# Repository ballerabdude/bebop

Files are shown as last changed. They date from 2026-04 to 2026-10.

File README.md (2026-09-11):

# Bebop

Bebop is an NVIDIA Jetson–based robot platform. This monorepo contains
everything needed to design, simulate, build, provision, and update a fleet
of Bebop robots — plus the customer-facing companion app.

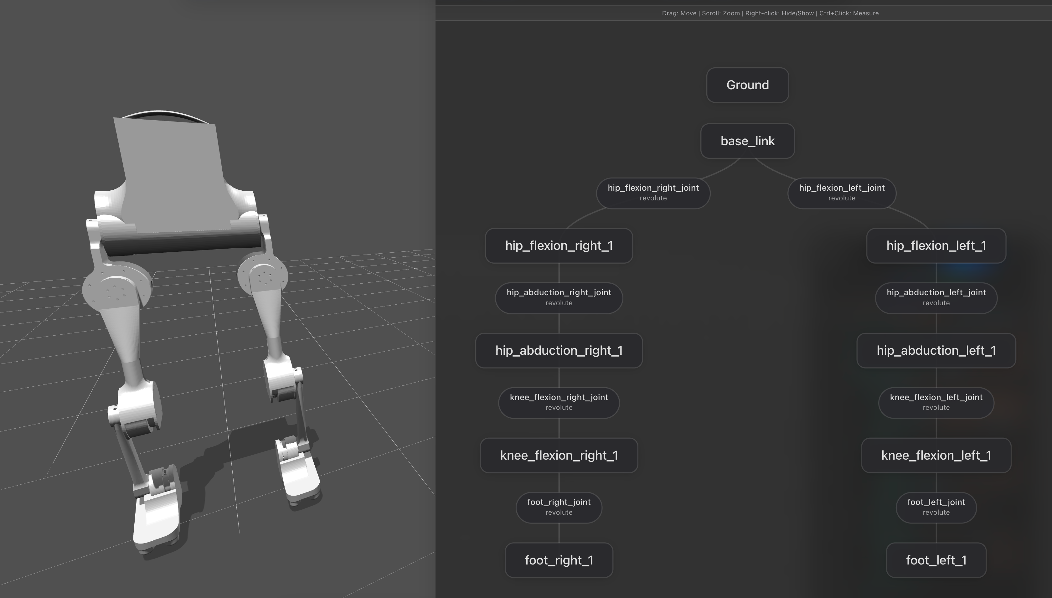
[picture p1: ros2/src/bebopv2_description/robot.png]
Bebop robot


## High-Level Architecture

```
 ┌────────────────────┐  SoftAP + WS :9091  ┌──────────────────────────┐
 │  Mobile App        │ ──────────────────▶ │  bebop-agent (Rust)      │
 │ (iOS / Android)    │ ◀──── status ────── │  running on Jetson       │
 └─────────┬──────────┘                     │  ┌────────────────────┐  │
           │  Wi-Fi / LAN                    │  │ Wi-Fi provisioner  │  │
           │                                 │  │ SoftAP fallback    │  │
           │  runtime WS :9090               │  │ Setup server       │  │
           ▼                                 │  └────────────────────┘  │
 ┌────────────────────┐                      └──────────────────────────┘
 │  bebop-linux       │
 │  (Rust firmware)   │──── SocketCAN ── motors
 └────────────────────┘
```

## Repository Layout

| Path | Purpose |
|---|---|
| `jetson-flash/` | One-time host-side provisioning: downloads NVIDIA L4T and flashes a fresh Jetson Orin Nano over USB. Runs once per device. |
| `jetson-agent/` | Rust workspace + on-device deployables. `bebop-agent` provisioning daemon (Wi-Fi + SoftAP), `bebop-proto` (setup wire format), `deploy/` (systemd + install scripts). |
| `bebop-app/` | Customer-facing companion app (Tauri 2 + React + TypeScript). Desktop / iOS / Android. |
| `firmware/` | Embedded firmware: `bebop-linux/` (Rust runtime) and `bebop-locomotion/` (PlatformIO). C/C++ tooling pinned via `firmware/.clangd`. |
| `bebop-vision/` | Robot vision stack: SAM 3.1 teacher pipeline (dataset auto-labeling + distillation) and the SegFormer navigable-path student, sector planner, and drive tooling. See `bebop-vision/README.md`. |
| `sim/` | Isaac Sim / Isaac Lab containers, the `bebop_training` Python RL extension, and `usd/` scene assets. Runs off-robot on a workstation with an NVIDIA GPU. |
| `ros2/` | ROS 2 Jazzy workspace used on the dev workstation: `src/bebop_pilot`, `src/bebopv2_description` (URDF), and the dev container under `docker/`. |
| `docs/` | Cross-cutting docs: architecture, setup protocol, onboarding, hardware reference. |
| `docker-compose.yml`| Orchestrates the dev-workstation containers (`ros2_docker`, `isaac_sim`, `isaac_lab`) under the `sim` / `lab` profiles. |
| `justfile` | Convenience recipes (`just check`, `just build-jetson`, `just sim-up`, `just lab-up`, ...). |
| `.github/` | CI workflows. |

## Getting Started

Read [`docs/onboarding.md`](docs/onboarding.md) for dev setup, your first
build, and how to deploy to a real Jetson. Then `docs/architecture.md`
shows how the on-robot pieces connect.

```sh
just                # list available recipes
just check          # workspace-wide cargo check (jetson-agent)
just build-jetson   # native arm64 build of the agent (run on arm64 Linux)
just app-dev        # run the mobile app in Tauri dev mode
just sim-up         # bring up Isaac Sim + ROS 2 dev container
just lab-up         # bring up Isaac Lab + ROS 2 dev container
```

## Naming

The robot product is **Bebop**. The on-device daemon is **bebop-agent**.
The companion app is also called **Bebop** (binary: `bebop-app`).

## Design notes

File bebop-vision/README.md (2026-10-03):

# bebop-vision

Data-collection and dataset-labeling stack for the bebop robot: the
Orbbec RGB-D rig is recorded into **navd MCAP sessions** (dual-camera
color + lossless depth + cmd_vel/odom/goal + a geometric BEV teacher
grid), auto-labeled with SAM 3.1 floor concepts fused by measured depth,
and reviewed/corrected in a dashboard — the dataset any navigation
approach (learned or classical) trains and evaluates from.

This tree intentionally carries **no driving code**. Drive the robot
from the app (manual teleop); the recorder captures whatever you do.
The navigation research (BEV student, end-to-end trajectory student,
TensorRT runtime) lives on the `exp/navd-ai-20260909` branch.

## How a session becomes training data

```
 record            extract              SAM 3.1 labels          fuse                    review
 teleop + app ----> navd MCAP  --------> tools/sam_floor_label -> tools/fuse_navd_labels -> dashboard
 goals + odom      (tools/             (floor/carpet/rug/     (SAM floor gated by     (paint corrections
 (app Navigate)    mcap_extract.py)    ground per camera)     measured depth -> 60x60  as `hand` labels)
                                                              teacher per tick)
```
(The recorded MCAP carries no BEV grid — labels are generated purely
from SAM × measured depth.)

- **Record** — `main.py --record-navd <dir> --auto` opens/closes MCAP
  segments with the drive state (wheels armed, no estop) and prunes under
  a disk budget. Navigation goals from the app are recorded per tick —
  **teleop toward an active waypoint**: goals in the data are the signal
  goal-following models train on.
- **Extract** — `tools/extract_all_navd.py` unpacks MCAPs into
  `datasets/navd-v0/<session>/{color,color_far,depth,labels,manifest.jsonl}`.
- **Label** — `tools/sam_floor_label.py near|far` prompts SAM 3.1 with
  drivable-ground concepts per frame; `tools/fuse_navd_labels.py` gates
  SAM's floor by measured depth into a 60×60 teacher grid per tick
  (`blocked / navigable / caution`).
- **Review** — `tools/dashboard_api.py` (dashboard UI): replay ticks,
  compare fused teacher vs prediction overlays, paint corrections as
  additive `hand` labels. A session counts when it passes review.

## Layout

| Path | Purpose |
|---|---|
| `main.py` | Entry point: navd MCAP recorder (rig + operator video + goals) |
| `bebop_vision/orbbec.py` | Orbbec rig: cameras, sync, intrinsics, rig YAML |
| `bebop_vision/camera.py` | Threaded MJPEG/RTSP/file consumer with reconnect |
| `bebop_vision/robot.py` | Protobuf-over-WS runtime client (telemetry, goals) |
| `bebop_vision/videoserver.py` | Operator WebRTC (WHEP) streams (`:9092/whep?stream=...`) |
| `bebop_vision/whep.py` | webrtcbin H.264 pipeline + offer/answer per client |
| `bebop_vision/recorder_mcap.py` | navd MCAP writer (10 Hz ticks, shared log_time) |
| `bebop_vision/sam3_concepts.py` | SAM 3.1 text-prompted concept segmenter (teacher) |
| `bebop_vision/goals.py` | Navigation-goal slot (heading / odom point) |
| `tools/mcap_extract.py` | MCAP session -> navd-v0 training layout |
| `tools/extract_all_navd.py` | Extract + audit every mirrored session |
| `tools/sam_floor_label.py` | SAM 3.1 floor labels per extracted session |
| `tools/fuse_navd_labels.py` | SAM × depth -> fused 60×60 teacher grids |
| `tools/dashboard_api.py` | FastAPI backend for the review dashboard |
| `dashboard/` | Review dashboard (React): replay, overlay, hand painting |
| `tools/set_self_mask.py` | Chassis self-view mask painter |
| `tools/orbbec_imu_probe.py` | Camera IMU (accel/gyro) profiles + depth-clock offset probe |
| `weights/` | Checkpoints (gitignored) |
| `datasets/` | Extracted datasets (gitignored) |

Navigation research (BEV student, trajectory student, TensorRT runtime,
drive paths) lives on the `exp/navd-ai-20260909` branch — including its
own README additions and `docs/navd-traj.md`.

## Install

Robot + workstation runtime:

```sh
python -m venv .venv
.venv/bin/pip install -e .
```

Labeling side (workstation with NVIDIA GPU — SAM 3.1 teacher):

```sh
.venv/bin/pip install "sam3 @ git+https://github.com/facebookresearch/sam3.git" psutil
# sam3 pulls torchvision from PyPI, which will NOT match a cu128 torch build.
# Reinstall it from the same index torch came from, e.g.:
.venv/bin/pip install --force-reinstall --no-deps "torchvision==0.26.0+cu128" \
    --index-url https://download.pytorch.org/whl/cu128
```

### Model weights

The robot does not ship weights. `config/models.yaml` is the catalog (shared
with the firmware): each entry is either `kind: hf` (download from Hugging
Face) or `kind: local` (trained on the robot, or copied from a workstation
with `scp`), and carries a `purpose` (e.g. `segmentation`, `backbone`,
`navigation`). Models sharing a purpose are alternatives. Add a model by
appending a catalog entry — no code changes.

**From the app (recommended):** *Configure models* on the Dashboard, the
Motor Bench footer (or the direct-connect screens) opens the **Models**
screen. It lists the catalog grouped by purpose, downloads on demand, and
lets the operator pick the active model per purpose. Gated entries need a
Hugging Face token, which the app sends to the robot (stored root-only at
`/etc/bebop/hf_token`, never echoed back). The token's account must have
accepted each model's license first, e.g.
<https://huggingface.co/facebook/sam3.1>. The purpose→model choice is
persisted at `/etc/bebop/model_selection.json` for the runtime to read. The
robot must be in Known Network (client) mode with internet during the
download; the firmware drives `bebop-model-download@<id>.service` and streams
progress into telemetry.

**On the workstation / by hand:**

```sh
# Put HF_TOKEN in .env (gitignored) or export it, then:
.venv/bin/python -m bebop_vision.download_model sam3.1   # one catalog id
.venv/bin/python -m bebop_vision.download_model --all    # every hf entry

# Legacy compatibility wrapper (downloads sam3 + sam3.1):
.venv/bin/python -m bebop_vision.download_sam3
```

## Collecting data

1. On the Jetson: `.venv/bin/python main.py --record-navd /var/lib/bebop-captures --auto`
2. From the app: enable wheels, teleop. Segments open/close with the
   drive state automatically.
3. Follow `docs/data-collection.md` for the per-session protocol —
   especially **goal-conditioned legs** (app Navigate waypoint + teleop
   toward it), which are the rarest and most valuable kind of tick.
4. Pull to the workstation (`just pull-data`), extract + audit
   (`just extract`), then review in the dashboard
   (`tools/dashboard_api.py`, port 8099).

## License note

SAM 3.x code and weights (teacher tooling, `weights/sam3*.pt`) are Meta's
"SAM License" — commercial use and fine-tuning are permitted and you own
derivative works, but redistribution of SAM 3.x materials or derivatives
must carry the SAM License. Downstream artifacts you train from the
labels (e.g. distilled students) are plain torch artifacts with no such
restriction. See the header of `bebop_vision/sam3_concepts.py`.

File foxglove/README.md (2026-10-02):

# Foxglove tooling

Scripts and layout definitions for reviewing Bebop **policy capture** MCAP
recordings in [Foxglove](https://foxglove.dev/). Captures are now written as
**ROS2 CDR-encoded MCAP** (profile=`ros2`, schema=`ros2msg`, message=`cdr`)
by `firmware/bebop-linux/src/policy_capture.rs`.

## Quick start

1. Open an MCAP file in Foxglove Desktop.
2. Import a layout: **Layouts -> Import from file...** and choose one of the
   generated JSON files.
3. For the robot layout, set **Settings -> Desktop -> ROS_PACKAGE_PATH** to:
   ```
   /Users/ahagi/Documents/projects/bebop/ros2/src
   ```

Regenerate layouts after editing the Python sources:

```bash
python3 foxglove/make_foxglove_layout.py --layout all --force
```

## Channels

The ROS2 MCAP file contains 5 channels:

| Channel | ROS2 Type |
| --- | --- |
| `/joint_states` | `sensor_msgs/msg/JointState` |
| `/imu` | `sensor_msgs/msg/Imu` |
| `/policy/status` | `bebop_msgs/msg/PolicyStatus` |
| `/policy/observation` | `bebop_msgs/msg/Float32Stamped` |
| `/policy/action` | `bebop_msgs/msg/PolicyAction` |

## Layouts

### Robot (`bebop_robot_layout.json`)

- **3D panel** loads the URDF and animates from `/joint_states`
- **Plot panels** read from `/joint_states.position[]` / `.velocity[]`,
  `/imu.orientation` / `.angular_velocity`, with X axis `/policy/status.sim_time_s`

### Policy debug (`bebop_policy_layout.json`)

Same animated URDF **3D panel** as the robot layout, plus two plot columns
for debugging policy behavior tick by tick:

- **Inputs** (`/policy/observation.data[]`): base angular velocity,
  projected gravity, joint pos/vel (relative, scaled), and velocity
  commands — the exact 49-element vector fed to the network.
- **Outputs** (`/policy/action.*`): decoded position targets (rad), `kp`,
  and `kd`.

See `firmware/bebop-linux/src/observation.rs::build` for the observation
index layout.

### Noise (`bebop_noise_layout.json`)

2x2 mosaic for static-capture noise review.

### navd sessions (`bebop_navd_layout.json`)

Review layout for navd recorder-v2 MCAP sessions
(`bebop-vision/bebop_vision/recorder_mcap.py`). Image/video channels are
Protobuf-encoded Foxglove messages; the custom twist/odom/calib channels
are JSON:

- **Image panels**: `/color_near` + `/color_far` (`foxglove.CompressedVideo`
  H.265, hardware NVENC; falls back to `foxglove.CompressedImage` JPEG),
  `/depth_near` + `/depth_far` (16-bit PNG, turbo colormap)
- **Plots**: teleop twist `/cmd_vel.vx|.wz` (the imitation label), odometry
  `/odom.x|.y|.theta`

The protobuf encoding also lets the native [Rerun](https://rerun.io) viewer
open a session directly (`rerun <session>.mcap`): Rerun maps the color
channels to a `VideoStream` and the depth channels to images, decoding
H.265 via the system FFmpeg with no GPU. (The Rerun web viewer still needs
browser HEVC; Foxglove's WebCodecs has no software HEVC path.)

For the bebop_navd Rerun dashboard (camera grid + telemetry plots), open the
session through the launcher instead; it takes a local path or a capture URL
(cached under `~/.cache/bebop/captures`):

```bash
python rerun_dashboards/open.py \
    http://bebop.local:9090/captures/dl/navd_session_<stamp>.mcap
```

Plain `rerun <session>.mcap rerun_dashboards/bebop_navd.rbl` does *not*
apply the dashboard: the MCAP loader names the app after the file, and a
blueprint only applies to recordings with its own app id (`bebop_navd`).

Record a session on the robot, copy it off, open it here:

```bash
# robot
python main.py --record-navd /tmp/navd_sessions --seconds 600
# workstation
scp bebop@bebop.local:/tmp/navd_sessions/*.mcap datasets/sessions/
```

## MCAP noise analysis

```bash
pip install mcap
python3 foxglove/mcap_noise.py ~/bebop-captures/policy_capture_*.mcap
```

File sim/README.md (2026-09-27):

# sim/

Simulation, RL training, and 3D assets for Bebop. Everything in here runs
**off-robot** on a workstation with an NVIDIA GPU and Isaac Sim / Isaac Lab.

## Layout

| Path | What it is |
|---|---|
| `pyproject.toml` | Defines the `bebop_training` Python package (depends on `isaaclab`). |
| `bebop_training/`  | RL extension: agents, envs, experiments, model export. |
| `usd/` | USD scene assets (`bebopv2/` robot description for Isaac Sim). |
| `scripts/` | One-shot Isaac Sim utility scripts (run from the Script Editor). |
| `docker/` | Isaac Sim / Isaac Lab container image (single Dockerfile, two BASE_IMAGEs). |
| `logs/` | Training logs (gitignored). Bind-mounted into the Isaac Lab container. |
| `setup/thor/` | On-device Jetson AGX Thor (aarch64) training env: pinned native Isaac Lab + GR00T installers. See [`setup/thor/README.md`](setup/thor/README.md). |

## Containers

The Isaac Sim and Isaac Lab containers are defined in the repo-root
`docker-compose.yml` and built from `sim/docker/Dockerfile` (the same image
recipe is reused with two different `BASE_IMAGE` args).

When the container starts, `sim/docker/entrypoint.sh` pip-installs the
`bebop_training` package in editable mode from `/workspace/bebop_bot/sim`,
which is the bind-mounted host path of this folder.

## Thor (aarch64) on-device training

The containers above are x86_64. To train **on the robot** (Jetson AGX Thor),
use the pinned native environment under [`setup/thor/`](setup/thor/README.md):

```sh
just thor-isaaclab          # install/refresh Isaac Sim + Isaac Lab on the Thor
just thor-train --task Isaac-Ant --num_envs 256
just thor-groot             # install/refresh the GR00T N1.7 VLA stack
```

There is no official aarch64 Isaac Sim container, so Thor uses a venv instead
of `sim/docker`; GR00T uses NVIDIA's upstream Thor installer. See
[`setup/thor/README.md`](setup/thor/README.md) for version pins, the verified
results on this robot, and the known Thor gotchas.

## Common commands

From the repo root:

```sh
just sim-up      # Isaac Sim + ROS 2 dev container (profile: sim)
just lab-up      # Isaac Lab + ROS 2 dev container (profile: lab)
just sim-down    # tear down sim profile
just lab-down    # tear down lab profile
```

Or directly with compose:

```sh
docker compose --profile sim up --build
docker compose --profile lab up --build
```

## URDF → USD import

After regenerating `ros2/src/bebopv2_description/urdf/bebopv2.urdf` (see
[`ros2/README.md`](../ros2/README.md) → "URDF mesh paths"), convert it
to USD headlessly inside the Isaac Lab container:

```sh
just lab-urdf-to-usd
```

That runs [`scripts/urdf_to_usd_bebopv2.py`](scripts/urdf_to_usd_bebopv2.py),
which converts the URDF into the layered asset at `usd/bebopv2/`
(wiping the previous generated copy — recoverable from git), applies the
post-import fixes from [`scripts/post_import_bebopv2.py`](scripts/post_import_bebopv2.py),
and prints a sanity report (joint completeness, link masses, measured
sole height vs. the configured spawn lift). The fixes:

- disable the fixed root joint the importer may add (we need a
  free-floating base for the biped),
- ensure `base_link` is a dynamic (not kinematic) rigid body,
- translate the robot up by 0.765 m so it spawns with its feet on the
  ground plane (the URDF's `base_link` frame is at the hip; the sole
  sits 0.7302 m below it at zero pose, +35 mm settle clearance),
- attach a 200 Hz IMU prim (`Imu_Sensor`) under
  `<robot>/Geometry/base_link`, matching the on-robot BNO085 placement
  so the policy sees the same `/imu/data` shape in sim and on hardware,
- bake `PhysxContactReportAPI` onto both foot prims so Isaac Lab's
  `ContactSensor` surfaces ground-contact events.

Both scripts are idempotent — safe to re-run. If you need the GUI
importer instead (manual fallback with the same settings), see
[`ros2/README.md`](../ros2/README.md) → "Importing the URDF into Isaac
Sim".

After converting, sanity-check the asset with `just lab-play
--num_envs 1` — the env's joint-order assertion fails fast if the
re-import shuffled joints.

## Sim-to-real contract (READ BEFORE TRAINING)

The Bebop V2 sim is pinned to the firmware's actual control behaviour, not
to whatever the motors *could* do mechanically. If you change either side
without changing the other, the trained policy will diverge on hardware.
Recent symptom of a divergence: "robot stands in sim, falls over instantly
on the real robot — feels weightless in sim".

The contract lives in three places that must agree:

| Quantity | Sim source of truth | Firmware source of truth |
|---|---|---|
| Per-joint policy kp/kd clamps | `POLICY_KP_MIN/MAX` and `POLICY_KD_MIN/MAX` in [`bebop_v2_base_cfg.py`](bebop_training/envs/bebop_v2_base_cfg.py) | `joints.<joint>.policy_gain_clamps` (per joint) + `defaults.policy_gain_clamps` in [`bebop_v2.yaml`](../firmware/bebop-linux/config/bebop_v2.yaml) |
| Per-joint torque cap (`effort_limit_sim`) | `FW_*_TAU_MAX` in `bebop_v2_base_cfg.py` | `joints.<joint>.hard_limits.tau_max` in `bebop_v2.yaml` |
| Per-joint velocity cap (`velocity_limit_sim`) | `FW_*_VEL_MAX` in `bebop_v2_base_cfg.py` | `joints.<joint>.hard_limits.vel_max` in `bebop_v2.yaml` |
| Setpoint slew on position channel (rad / 100 Hz tick) | `FW_MAX_POS_STEP_PER_TICK_RAD` in `bebop_v2_base_cfg.py`, applied via [`VariableImpedanceJointAction`](bebop_training/envs/bebop_v2_actions.py) | `defaults.slew.max_pos_step_per_tick` in `bebop_v2.yaml`, enforced in [`safe_send_ctrl`](../firmware/bebop-linux/src/safety/supervisor.rs) |
| Action / actuation latency | `FW_ACTION_DELAY_STEPS` ticks of action delay in `VariableImpedanceJointAction` | one CAN round-trip @ 100 Hz tokio tick in [`policy_runner.rs`](../firmware/bebop-linux/src/policy_runner.rs) |
| 52-dim observation / 24-dim MIT-mode action layout | [`ObservationsCfg`](bebop_training/envs/bebop_v2_base_cfg.py) | [`observation.rs`](../firmware/bebop-linux/src/observation.rs) and [`policy_runner.rs`](../firmware/bebop-linux/src/policy_runner.rs) |

If you tune any of those numbers (e.g. raise `max_pos_step_per_tick` to
let the policy move faster, or widen a `policy_gain_clamps` range after
a motor swap), update **both** sides and **retrain** — the policy bakes
in the achievable bandwidth and the kp/kd envelope, and a checkpoint
trained against one slew rate / clamp set will not transfer to another.

## Training

Training runs **inside the Isaac Lab container** (`bebop_isaac_lab`)
using [`train_bebop.py`](train_bebop.py) — a thin rsl_rl PPO entry
point that lives in this directory. At container start
`docker/entrypoint.sh` pip-installs `bebop_training` in editable mode,
which registers all the Bebop V2 Gym tasks so `--task` finds them.

Inside the container the script is at
`/workspace/bebop_bot/sim/train_bebop.py` (the repo is bind-mounted at
`/workspace/bebop_bot/`).

### Get a shell

```sh
just lab-up                   # bring up Isaac Lab + bebop_ros2 (profile: lab)
just lab-shell                # exec into bebop_isaac_lab
cd /workspace/bebop_bot/sim   # where train_bebop.py + bebop_training/ live
```

### Registered tasks

These IDs come from [`bebop_training/__init__.py`](bebop_training/__init__.py):

| Task ID | Cfg | What it trains |
|---|---|---|
| `Isaac-BebopV2-Standing-v0` | `BebopV2StandingCfg` | Minimal quiet-standing baseline (zero velocity command). |
| `Isaac-BebopV2-Standing-FixedGain-v0`  | `BebopV2StandingFixedGainCfg`  | Standing with kp/kd structurally frozen at midpoints. |
| `Isaac-BebopV2-Standing-Push-v0` | `BebopV2StandingPushCfg` | Standing + mid-episode pushes with a magnitude curriculum. |
| `Isaac-BebopV2-Standing-Push-ActNet-v0`| `BebopV2StandingPushActNetCfg` | Push-stand with the learned torque-response actuator (td-b05f58). |
| `Isaac-BebopV2-Mirror-v0` | `BebopV2MirrorCfg` | Visual hardware telemetry mirror (not for RL training). |

### Actuator-net (learned torque response)

The `ActNet` task swaps each `DCMotorCfg` group for a hybrid actuator
([`bebop_training/envs/bebop_v2_actuator_net.py`](bebop_training/envs/bebop_v2_actuator_net.py)):
analytic PD from the policy's live gains, then a learned cmd→realized-torque
response net (3×64 softsign MLP per Robstride motor model), then the usual
DC speed-torque envelope as a hard rail. Train the nets from the sysid logs
and smoke-test the integration before training:

```sh
# inside the Isaac Lab container, CWD=/workspace/bebop_bot/sim
/workspace/isaaclab/isaaclab.sh -p bebop_training/tools/actuator_net_fit.py
/workspace/isaaclab/isaaclab.sh -p scripts/verify_actuator_net.py --headless
```

The fit tool reads `bebop-sysid-logs/` and writes TorchScript nets +
`meta.json` (with net-vs-baseline RMSE) to `bebop_training/assets/actuator_nets/`.
Policy I/O is unchanged, so ActNet checkpoints deploy through the normal
ONNX path.

### Retraining after a sim-to-real fix

If you've just changed any of the `FW_*` constants in
`bebop_v2_base_cfg.py` (or the matching firmware fields in
`bebop_v2.yaml`), the existing checkpoints under `sim/logs/rsl_rl/` are
stale — they were trained against a different control surface and will
collapse on hardware. Retrain the curriculum from scratch (do not
`--resume` an old checkpoint that pre-dates the fix; it will hurt more
than it helps because the actor's converged action distribution is tuned
to the old physics).

The first stage (`Isaac-BebopV2-Flat-v0`) runs in ~45 min on a single
RTX 5090 at `--num_envs 4096`; the full curriculum is ~3 hours.

### Curriculum (recommended)

Train in sequence, warm-starting locomotion from the balance checkpoint.
The balance task is now a single merged stage that trains both standing
*and* push recovery (initial-condition randomisation + periodic lateral
pushes are wired into `BebopV2BaseEnvCfg.EventCfg`), so a separate
"robust" stage is no longer needed. See the long-form discussion in
[`experiments/exp_flat_balance_v2.py`](bebop_training/experiments/exp_flat_balance_v2.py)
and
[`experiments/exp_flat_locomotion_v2.py`](bebop_training/experiments/exp_flat_locomotion_v2.py).

```sh
# Stage 1 — stand + push recovery (single merged task)
/workspace/isaaclab/isaaclab.sh -p train_bebop.py \
    --task Isaac-BebopV2-Flat-v0 \
    --num_envs 512 --seed 42 --visualizer newton

# Stage 2 — locomotion (warm-start from stage 1)
/workspace/isaaclab/isaaclab.sh -p train_bebop.py \
    --task Isaac-BebopV2-Locomotion-v0 \
    --num_envs 512 --seed 42 --visualizer newton \
    --resume logs/rsl_rl/Isaac-BebopV2-Flat-v0/<run>/model_4000.pt \
    --reset_action_std 0.5
```

Substitute the actual run timestamp under `logs/rsl_rl/<task>/` for
`<run>` (rsl_rl auto-creates a timestamped subdir per run). Pick a
checkpoint that has converged — `model_4000.pt` is a reasonable
default for the balance stages; check the TensorBoard reward curves
and use a later one if it's still improving.

### Useful flags

| Flag | Purpose |
|---|---|
| `--task` | Gym ID — see "Registered tasks" above. |
| `--num_envs` | Parallel envs (512 is a good default on a single 4090; scale to GPU mem).  |
| `--seed` | RNG seed for reproducibility. |
| `--visualizer newton` | Use the Newton renderer (faster than the default Kit viewport for headless training). |
| `--resume <path>` | Warm-start from an existing checkpoint (used for curriculum chaining). |
| `--reset_action_std 0.5` | Re-inject exploration noise after `--resume`. Without this, a converged policy's tiny action std stays tiny across the curriculum boundary and PPO can't escape the previous stage's local optimum. |
| `--headless` | Disable the GUI (default for batch training; omit if you want to watch). |

### Logs and checkpoints

`rsl_rl` writes logs and checkpoints to `logs/rsl_rl/<task>/<run>/`,
which is bind-mounted onto the host at `sim/logs/` (see the `isaac_lab`
service in `docker-compose.yml`). Inspect with TensorBoard:

```sh
# On the host:
tensorboard --logdir sim/logs/rsl_rl
```

### Exporting a trained policy

After Stage 3 converges, export the policy to ONNX for the on-robot
runner ([`bebop_pilot/policy_runner`](../ros2/src/bebop_pilot/)):

```sh
/workspace/isaaclab/isaaclab.sh -p \
    /workspace/bebop_bot/sim/bebop_training/export_bebop_model.py \
    --task Isaac-BebopV2-Locomotion-v0 \
    --checkpoint logs/rsl_rl/Isaac-BebopV2-Locomotion-v0/<run>/model_<N>.pt
```

The resulting `policy.onnx` is what `bebop_pilot bringup.launch.py`
consumes via the `model_path:=...` launch argument on the Jetson.

## Hardware pose mirror

`mirror_bebop.py` spawns a single Isaac Lab robot and teleports its joints
(and base orientation from the IMU) to match live hardware telemetry from
`bebop-linux` over the runtime WebSocket API (`bebop_runtime.proto` on
`ws://<robot-ip>:9090/ws`). Base XY stays fixed at the spawn pose — the
real robot has no odometry.

1. Start `bebop-linux` on the robot (or locally) with motors reporting
   (Idle or DialIn).
2. In the Isaac Lab container (Kit viewport is the default; use ``--viz newton``
   for the Newton renderer instead):

```sh
/workspace/isaaclab/isaaclab.sh -p /workspace/bebop_bot/sim/mirror_bebop.py \
    --robot-host 192.168.0.69 \
    --telemetry-hz 30

# Or with Newton:
/workspace/isaaclab/isaaclab.sh -p /workspace/bebop_bot/sim/mirror_bebop.py \
    --robot-host 192.168.0.69 \
    --viz newton
```

Use the robot's LAN IP when the runtime is not on the same host. With
compose host networking, `127.0.0.1:9090` works when `bebop-linux` runs on
the workstation.

**Note:** mDNS hostnames like `bebop.local` usually do not resolve inside
the Isaac Lab container even with host networking. Use the robot IP from
`getent hosts bebop.local` on the host if needed.

Move a joint on hardware (e.g. DialIn to 0.8 rad) and confirm the sim
joint matches the same angle and sign.

**Firmware note:** joint positions only stream over CAN when motors are
reporting feedback. As of the telemetry-probe change, subscribing to WS
telemetry in Idle enables Robstride active reporting on disarmed joints
(same idea as the always-on IMU stream). Redeploy `bebop-linux` after
pulling firmware changes for mirror mode in Idle; in DialIn with motors
armed, positions already update via the hold cycle.

Regenerate Python protobuf bindings after editing
`jetson-agent/bebop-proto/proto/bebop_runtime.proto`:

```sh
protoc --python_out=sim/bebop_training/proto \
  --proto_path=jetson-agent/bebop-proto/proto \
  jetson-agent/bebop-proto/proto/bebop_runtime.proto
```

## DDS / ROS 2 bridge

Both Isaac containers and the ROS 2 dev container share
`ROS_DOMAIN_ID=0` and `RMW_IMPLEMENTATION=rmw_fastrtps_cpp` so topics
flow between them on the same host.

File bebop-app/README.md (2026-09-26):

# Bebop

The Bebop companion app. One customer-facing app for every interaction
with a Bebop robot — first-time setup, ongoing Wi-Fi configuration, motor
bench, and driving.

Built with [Tauri 2](https://tauri.app) + React + TypeScript + Vite.
Runs on desktop today and targets iOS and Android.

## Features

* **Setup wizard** — the robot broadcasts a `Bebop-XXXX` hotspot when it has
  no Wi-Fi. Join it, connect the app to the robot's setup server
  (`192.168.42.1:9091`), then scan/join your Wi-Fi and name the robot.
* **Dashboard** — live Wi-Fi state and a network-mode switch
  (`auto` / `client` / `ap`), plus access to the operator screens.
* **Connect by IP** — talk to the runtime controls server on a robot that is
  already on the network.
* **Motor bench** — live per-joint telemetry, dial-in slider with re-zero
  affordance, power-board card, sticky toolbar with E-STOP.
* **Live video** — the bebop-vision process's WebRTC (WHEP) streams
  (`:9092/whep?stream=...`): color + depth for both Orbbec cameras, each a
  toggleable tile (`VideoScreen`).
* **Teleop** — live video and driving in one screen (`TeleopScreen`): the
  primary stream front and center with other open streams docked as
  clickable thumbnails, a sticky HUD (link / mode / wheels / battery /
  E-STOP), a one-tap "Start driving" quick-start, and every input path side
  by side — on-screen joystick, WASD / arrows, or a gamepad connected to the
  device running the app.
* **App-side gamepad dial-in & drive** — connect an 8BitDo / DualSense /
  Xbox / Switch Pro pad to your phone or laptop and drive the active joint's
  target (legged) or the wheeled chassis directly. See
  [Gamepad controls](#gamepad-controls).

## Architecture

Two independent transports, split by purpose:

| Purpose | Talks to | Transport | Default port |
|---|---|---|---|
| Provisioning | `bebop-agent` (setup server)| `SetupTransport` — protobuf over binary WebSocket  | 9091 |
| Operating | `bebop-linux` (runtime) | `RuntimeTransport` — protobuf over binary WebSocket| 9090 |

`SetupTransport` (`src/ble/setupTransport.ts`) implements the
`BebopTransport` interface (`src/ble/transport.ts`) and provides Wi-Fi
scan/join, robot naming, and network-mode selection. It is reached either
over the robot's setup hotspot or over the LAN.

`RuntimeTransport` (`src/runtime/wsTransport.ts`) carries the high-rate
operator API — telemetry, modes, motor/wheel control, twists — using the
`bebop.runtime.v1.*` envelope and pushes telemetry at ~30 Hz.

Both envelopes are shared with the robot. TypeScript bindings are generated
by [`@bufbuild/protoc-gen-es`](https://github.com/bufbuild/protobuf-es) and
committed:

* `src/proto/bebop_pb.ts` — setup protocol (from `bebop.proto`).
* `src/proto/bebop_runtime_pb.ts` — runtime protocol (from `bebop_runtime.proto`).

Regenerate after editing a `.proto`:

```sh
npm run gen-proto
```

## Gamepad controls

The app-side gamepad flows use the
[Web Gamepad API](https://developer.mozilla.org/en-US/docs/Web/API/Gamepad_API)
and work with any pad the browser/WebView surfaces. The pad stays paired to
the device running the app and streams commands over the runtime WS — the
robot's own Bluetooth stack is not involved.

| Flow | Drives | Where it lives |
|---|---|---|
| App-side dial-in  | Per-joint target position via `setMotorTarget` (legged) | `src/input/`, `src/components/GamepadDriver.tsx` |
| App-side drive | Body twist (vx, wz) via `setVelocityCommand` (wheeled) | `src/input/`, `src/components/GamepadDrive.tsx`  |

### Layout auto-detection

The driver supports both common HID layouts and picks one per pad in
`src/input/mapping.ts`:

| Layout | Picked when | Examples |
|---|---|---|
| `standard`  | `Gamepad.mapping === "standard"` | Xbox Wireless, DualSense over BT, 8BitDo in **X-input** mode (hold START + Y for 3 s) |
| `dinput` | Anything else (8BitDo / generic HID) | 8BitDo Mobile / Pro 2 / Zero 2 in their default Android mode, generic HID pads |

The active layout name appears as a small badge on the controller card. Each
layout knows the chord text printed on its physical pad, so the on-screen
hints read **"LB / RB"** under standard and **"L1 / R1"** under D-input.
Logical intents (`prevJoint`, `nextJoint`, `deadman`, `estop`, `resetEStop`,
`armToggle`) are the same across layouts; consumers read `snapshot.logical.*`
and don't deal with raw button indices.

### Bindings

**Motor bench (legged dial-in):**

* **LB / L1**, **RB / R1** — cycle the active joint
* **Left stick ↕** — nudge the active joint's target (rate scaled by trigger)
* **RT / R2** held — deadman; release to halt immediately
* **L3** — arm / disarm the active joint
* **B / Circle** — latch the runtime E-STOP
* **A / Cross** — clear a latched E-STOP

**Wheeled drive** (motor bench + teleop):

* **Sticks** — drive in *split* (default: left ↕ forward, right ↔ turn) or
  *arcade* (left stick does both) layout; toggled on the card, persisted per
  device. On the teleop screen with a camera, the right stick aims the camera
  instead and the layout locks to arcade.
* **RT / R2** held — deadman; release to halt immediately. Trigger pressure
  scales the request.
* **L3** — arm / disarm all wheels
* **B / Circle** — latch the runtime E-STOP
* **A / Cross** — clear a latched E-STOP

The firmware holds the last commanded twist until told otherwise, so the
bridge owns stopping: deadman release, E-STOP latch, pad disconnect, leaving
the screen, hiding the tab, or any interruption of the gamepad poll loop
(250 ms watchdog) all enqueue a zero twist exactly once per drive cycle.

### Control profiles

How sensitive the controls feel is a per-device setting switched in the app —
pickers live on the drive card and both gamepad cards. A profile sizes every
app-side input path at once and persists in localStorage under
`bebop.controlProfile`. Defined in `src/input/profile.ts`:

| Profile | Stick deadzone | Expo | Drive limits | Dial-in rate |
|---|---|---|---|---|
| Gentle | 18% | 0.5  | 0.5 m/s · 1.0 rad/s | 1.0 rad/s |
| Standard | 12% | — | 1.0 m/s · 2.0 rad/s | 2.0 rad/s |
| Sport | 8% | — | 1.5 m/s · 3.0 rad/s | 3.0 rad/s |

The firmware still clamps twists to each wheel's `vel_max` and dial-in steps
to `slew.max_pos_step_per_tick`, so a faster profile can't exceed the robot's
hard ceilings.

### Keyboard chords per screen

| Screen | Drive (vx / wz)  | Camera PTZ |
|---|---|---|
| Video | — | WASD + arrows |
| Teleop | WASD + arrows | I / J / K / L |

Every pad stops-on-exit: keys held at unmount or at a `disabled` flip enqueue
a stop/hold exactly once.

## Running on the robot

For bench work, the app can be served from the Jetson itself so any device on
the same network (or the robot's Hosted Network) can open the UI in a browser:

```sh
# on the robot, from the repo root
cd bebop-app && npm install          # once
sudo ./bebop-app/deploy/install-app-dev.sh   # installs + enables the unit
```

This installs `bebop-app.service`, which runs `deploy/dev-server.sh`
(`npm run dev`) as the `bebop` user on boot. Vite serves on `0.0.0.0:1420`
(`vite.config.ts`), so open `http://bebop.local:1420` or
`http://<robot-ip>:1420`. It's a development server, not a production build.

## Developing

```sh
# from bebop/bebop-app
nvm use        # use the node version from .nvmrc
npm install
npm run tauri dev      # desktop dev build
npm run tauri android init && npm run tauri android dev
npm run tauri ios init && npm run tauri ios dev
```

Prerequisites:

* Node 20+ (managed via `nvm`)
* Rust toolchain (`rustup` stable)
* `protoc` on `PATH` (for regenerating bindings). On macOS:
  `brew install protobuf`. On Debian/Ubuntu:
  `sudo apt-get install -y protobuf-compiler`.
* For mobile: Android Studio / Xcode toolchains (see Tauri docs)

## Repo layout

```
bebop-app/
├── src/                  # React + TypeScript UI
│   ├── App.tsx           # App shell + flow orchestration
│   ├── ble/              # SetupTransport + BebopTransport interface + types
│   ├── runtime/          # bebop-linux runtime WS client (motor bench, teleop)
│   ├── input/            # Web Gamepad API hook + per-layout button mapping
│   ├── proto/            # Generated protobuf bindings (npm run gen-proto)
│   │   ├── bebop_pb.ts            # Setup envelope
│   │   └── bebop_runtime_pb.ts    # bebop-linux runtime envelope
│   ├── components/       # Shared UI primitives + input bridges
│   │   ├── VideoFeed.tsx          # WebRTC feed tile (video/teleop)
│   │   ├── DriveJoystick.tsx      # Differential-drive pad (bench/teleop)
│   │   └── GamepadDriver/Drive    # Web-gamepad → dial-in / drive bridges
│   └── screens/          # Welcome, ConnectByIp, Wifi, Config, Dashboard,
│                         # MotorBench, Teleop, Video
├── src-tauri/            # Rust / Tauri shell
│   └── src/lib.rs        # Tauri builder
├── buf.gen.yaml          # protoc-gen-es codegen config (TS bindings)
└── README.md
```

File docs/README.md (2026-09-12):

# Bebop Docs

Cross-cutting documentation for the Bebop platform. Per-component READMEs
(Cargo crate docs, mobile-app dev notes, deploy scripts, etc.) live next
to the code they describe.

| Doc | What it covers |
|---|---|
| [`onboarding.md`](onboarding.md) | Dev-machine setup, first build, deploying to a Jetson, mobile app dev. |
| [`architecture.md`](architecture.md) | The components (`jetson-agent/`, `bebop-app/`, `firmware/`), boot sequence, and trust boundaries. |
| [`setup-protocol.md`](setup-protocol.md) | The `bebop-agent` setup WebSocket, Hosted Network provisioning flow, and network modes. |
| [`navd.md`](navd.md) | Depth-camera obstacle avoidance: dual Gemini 335Lg → BEV occupancy → goal-conditioned planner → learned student (design + phased spec). |

If you're new, read them in the order above.

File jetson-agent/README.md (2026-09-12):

# jetson-agent/

Everything that runs **on the Jetson** in support of provisioning.

| Path | What it is |
|---|---|
| `bebop-agent/`  | The Rust provisioning daemon (systemd service). Owns Wi-Fi setup + Hosted Network.  |
| `bebop-proto/`  | Shared protobuf schema for the setup wire protocol (WS on `:9091`). |
| `deploy/` | Systemd unit, install/uninstall scripts, example `agent.toml`. |
| `Cargo.toml` | Workspace root (`bebop-agent` + `bebop-proto`). |
| `rust-toolchain.toml` | Pinned Rust toolchain for the workspace. |

## Quick reference

All recipes live in the repo-root `justfile`:

```sh
just check          # cargo check --workspace --all-targets
just test           # cargo test --workspace
just lint           # cargo clippy --workspace --all-targets -- -D warnings
just build-jetson   # cargo build --release -p bebop-agent (run on arm64 Linux)
just deploy HOST    # scp + rsync + install on a robot
```

If you'd rather call cargo directly, do it from inside this folder:

```sh
cd jetson-agent
cargo build --workspace
```

## Why this is its own folder

The agent + its deploy scripts ship together to the Jetson. Keeping them
under one roof means:

- one Rust workspace (`Cargo.toml`, single `Cargo.lock`, single `target/`)
- the install script's `WORKSPACE_ROOT` walk lands on `jetson-agent/`,
  where `target/release/bebop-agent` lives
- adding more on-device pieces later doesn't pollute the repo root

The customer-facing mobile app is intentionally outside this folder — it
runs off-device and has its own build toolchain. See `../bebop-app/`.

## Provisioning flow

The agent serves a protobuf-over-WebSocket setup server on `:9091`. When the
robot has no usable Wi-Fi it also hosts a `Bebop-XXXX` hotspot so a phone can
join and reach that server at `192.168.42.1:9091`. See
[`../docs/setup-protocol.md`](../docs/setup-protocol.md).

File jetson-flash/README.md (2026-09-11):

# jetson-flash/

One-time, **host-side** provisioning of a fresh Jetson Orin Nano Super
Developer Kit with Jetson Linux. Defaults to the latest release
**L4T 39.2.0 / JetPack 7.2** (Ubuntu 24.04, kernel 6.8), which now supports
the Orin Nano series. The older **L4T 36.4.4 / JetPack 6.2.1** (Ubuntu 22.04,
kernel 5.15) is still selectable.

This sits at the very start of the Jetson lifecycle:

```
  bare board
      │
      ▼
  jetson-flash/   ← you are here (factory flash, ~once per device)
      │
      ▼
  jetson-agent/   ← the provisioning daemon that runs on every boot
      │
      ▼
  bebop-app       ← join the robot's hotspot, set up Wi-Fi
```

Use this folder when:

- You just received a new Orin Nano and need to put L4T on it.
- You bricked one and need to reflash.
- You want to bake a custom rootfs (e.g. with extra packages
  pre-installed) before the agent ever runs.

For day-to-day work on a *flashed* Jetson, you don't need anything in here.

## Prerequisites

- A Linux host PC (Ubuntu 20.04 or 22.04 recommended). Won't work from
  macOS — `apply_binaries.sh` needs Linux loop-mounting.
- At least 50 GB of free disk space.
- A USB-C cable to connect the Jetson to your host PC.

## Step 1: Download and prepare the L4T environment

`setup_env.sh` automates the NVIDIA download dance:
fetch the L4T Driver Package + Ubuntu sample rootfs, extract them, install the
host flashing prerequisites, and run `apply_binaries.sh` to install NVIDIA's
proprietary drivers into the rootfs.

```bash
cd jetson-flash
chmod +x setup_env.sh
./setup_env.sh            # defaults to L4T 39.2.0 (JetPack 7.2)
```

To pin a specific release, pass the version as an argument (or via the
`L4T_VERSION` env var). Supported values are `39.2.0` and `36.4.4`:

```bash
./setup_env.sh 36.4.4    # legacy JetPack 6.2.1
```

You will be prompted for your `sudo` password during the extraction phase.

After it completes, you'll have a `Linux_for_Tegra/` subdirectory here —
that's NVIDIA's flashing toolchain. **`Linux_for_Tegra/` is gitignored**;
it's regenerated by re-running `setup_env.sh`.

## Step 2: Create a default user

Before flashing, seed the rootfs with a default user so you can log in
after first boot.

```bash
cd jetson-flash/Linux_for_Tegra
sudo ./tools/l4t_create_default_user.sh -u bebop -p <password> -a -n jetson-nano
```

(Replace `<password>` and `jetson-nano` with whatever you want.)

## Step 3: Put the Jetson into Force Recovery Mode (FC RCM)

1. Power off the Jetson.
2. Connect it to the host PC over USB-C.
3. Place a jumper across the **FC REC** and **GND** pins on the button
   header.
4. Connect the power supply to power on the Jetson.
5. Remove the jumper.
6. Verify the host sees it:

   ```bash
   lsusb | grep NVIDIA
   ```

   You should see an "NVIDIA Corp." device.

## Step 4: Flash the Jetson

### L4T 39.2.0 / JetPack 7.2 (default)

The 39.2 flow simplifies the command considerably. This flashes the
**Jetson Orin Nano Super Developer Kit** over the USB-C cable (the
host↔device flashing link) and installs the OS onto the on-board NVMe.
Run `l4t_initrd_flash.sh` from `Linux_for_Tegra/`:

```bash
cd jetson-flash/Linux_for_Tegra
sudo ./tools/kernel_flash/l4t_initrd_flash.sh \
    --erase-all \
    --showlogs \
    --network usb0 \
    jetson-orin-nano-devkit-super internal
```

The partition layout and QSPI bootloader configs are now resolved
automatically from the board config, so the explicit `-c`/`-p` XML flags
are no longer required.

| Flag / argument | What it does |
|---|---|
| `--erase-all` | Erase all data on the target boot media before flashing. |
| `--showlogs` | Stream detailed flash logs. |
| `--network usb0` | Use the USB-network interface for the initrd flashing handshake. |
| `jetson-orin-nano-devkit-super`  | Board config for the Super Developer Kit. |
| `internal` | Install the OS to the device's on-board NVMe. |

Note: `internal` selects the NVMe target; the USB-C cable is only the
flashing connection. (If you ever needed to install onto USB-stick or
SD-card storage instead, you'd add `--external-device sda1` or
`--external-device mmcblk0p1` before the board config — not your case here.)

### L4T 36.4.4 / JetPack 6.2.1 (legacy)

If you provisioned with `./setup_env.sh 36.4.4`, use the older,
more explicit invocation:

```bash
cd jetson-flash/Linux_for_Tegra
sudo ./tools/kernel_flash/l4t_initrd_flash.sh \
    --external-device nvme0n1p1 \
    -c tools/kernel_flash/flash_l4t_t234_nvme.xml \
    -p "-c bootloader/generic/cfg/flash_t234_qspi.xml" \
    --showlogs \
    --network usb0 \
    jetson-orin-nano-devkit-super nvme0n1p1
```

## Step 5: Boot up

After a successful flash the Jetson reboots automatically. Disconnect the
USB-C cable, attach a monitor + keyboard, and log in with the user from
Step 2.

From there, follow [`docs/onboarding.md`](../docs/onboarding.md) under
"Running the agent on a Jetson" to install `bebop-agent`.

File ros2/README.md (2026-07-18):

# ros2/

ROS 2 Jazzy workspace used on the **dev workstation** — bringup, MoveIt
configs, joint-state publishers, robot description, etc. This is *not* what
runs on the Jetson at runtime (see `jetson-agent/` for that).

The container also acts as the **micro-ROS agent host**: it bridges the
Teensy locomotion controller (firmware in `firmware/bebop-locomotion/`,
running the `[env:ros]` build) to the rest of the ROS 2 graph via USB
serial.

## Layout

| Path | What it is |
|---|---|
| `src/bebop_pilot/` | High-level pilot / behaviour package. |
| `src/bebopv2_description/` | URDF + meshes + xacro for the robot. |
| `src/ros2.repos` | `vcstool` manifest for additional source dependencies. |
| `docker/Dockerfile` | Jazzy-desktop-full base + nav2 / MoveIt / ros2_control / ros-gz. |
| `docker/entrypoint.sh` | Bootstraps micro-ROS, builds the workspace, sources the overlay. |
| `docker/requirements.txt` | Python deps installed into the container's `/opt/venv`. |

`build/`, `install/`, `log/`, and `src/{micro_ros_setup,uros}/` are
gitignored — they're regenerated by the entrypoint or `colcon`.

## Architecture

```
┌────────────────────────────────────────────────────────────────────┐
│              Dev workstation — bebop_ros2 container                │
│                                                                    │
│  ┌──────────────┐  ┌───────────────┐  ┌──────────────────────┐    │
│  │ bebop_pilot  │  │ teleop / ...  │  │ Nav2 / MoveIt / ...  │    │
│  └──────┬───────┘  └───────┬───────┘  └──────────┬───────────┘    │
│         │                  │                     │                │
│         └────────── DDS (RMW_FASTRTPS) ──────────┘                │
│                            │                                      │
│                ┌───────────┴────────────┐                         │
│                │   micro_ros_agent      │                         │
│                │   serial_dev:/dev/ttyACM0                        │
│                └───────────┬────────────┘                         │
└────────────────────────────┼────────────────────────────────────--┘
                             │ USB Serial (bind-mount /dev)
                             │
            ┌────────────────▼────────────────────┐
            │     Teensy 4.1 (firmware/bebop-     │
            │     locomotion, env=ros)            │
            │                                     │
            │     /dev/ttyACM0  micro-ROS client  │
            │     /dev/ttyACM1  debug serial      │
            └─────────────────────────────────────┘
```

Both Isaac containers and `bebop_ros2` share `ROS_DOMAIN_ID=0` and
`RMW_IMPLEMENTATION=rmw_fastrtps_cpp` so topics flow across containers
on the same host.

## Why the workspace is host-side

`src/` lives on the host and is bind-mounted into the container at
`$ROS_WS/src` — i.e. `/home/<your-host-user>/master_ros2_ws/src`,
where `<your-host-user>` is baked in at image-build time from the
`$USER` env var on the host. That way `colcon build` artifacts
(`build/`, `install/`, `log/`) can stay inside the container while you
edit packages from your host IDE.

> Inside the container, prefer the `$ROS_WS` env var (set as a Docker
> `ENV` in the Dockerfile) over `$USER`. The compose `command: bash`
> launches a non-login shell, so `$USER` is **not** populated; commands
> like `cd /home/$USER/...` expand to `cd /home//...` and fail. `$HOME`
> and `$ROS_WS` are baked into the image and always work.

The container is named `bebop_ros2` and joins both the `sim` and `lab`
docker-compose profiles, so any time you bring up Isaac Sim or Isaac Lab,
the ROS 2 dev container comes along with it.

## URDF mesh paths

`src/bebopv2_description/urdf/bebopv2.urdf` references its meshes using
**absolute container paths** instead of the conventional
`package://bebopv2_description/...` or relative `../meshes/...` form:

```xml
<mesh filename="file:///workspace/bebop_bot/ros2/src/bebopv2_description/meshes/base_link.stl" .../>
```

This is deliberate. When the URDF is opened in **Isaac Sim** to be
converted to USD, the importer runs in a context where it cannot resolve
ROS-style `package://` URIs or relative paths — it doesn't have the
ROS package index loaded, and its working directory isn't the URDF's
parent. The only form it can reliably resolve is a `file://` URI
pointing at a path that exists **inside the Isaac Sim container**.

Because the Isaac containers bind-mount this repo root at
`/workspace/bebop_bot`, hard-coding that absolute path works everywhere
we care about: ROS 2 tooling (`robot_state_publisher`, RViz), Isaac
Sim's URDF importer, and Isaac Lab. If you move the repo mount point in
`docker-compose.yml`, you'll need to regenerate the URDF (or sed the
paths) to match.

### Regenerating the URDF from the xacro

`bebopv2.urdf` is a flat, mesh-path-rewritten artifact derived from
`bebopv2.xacro`. To regenerate it, use the helper script
[`src/bebopv2_description/scripts/xacro-to-urdf.sh`](src/bebopv2_description/scripts/xacro-to-urdf.sh),
which runs `xacro` and then rewrites every `<mesh filename="...">` to
an absolute prefix you control.

From the host (most convenient):

```sh
just ros2-urdf
# Override the mesh prefix:
just ros2-urdf --mesh-prefix /workspace/bebop_bot/ros2/src/bebopv2_description/meshes
# Preview without writing:
just ros2-urdf --check
```

Or directly inside `bebop_ros2`:

```sh
source /ros_ws_entrypoint.sh
"$ROS_WS"/src/bebopv2_description/scripts/xacro-to-urdf.sh
```

Defaults match what's currently committed:

| Flag | Default |
|---|---|
| `--in` | `src/bebopv2_description/urdf/bebopv2.xacro` |
| `--out` | `src/bebopv2_description/urdf/bebopv2.urdf` |
| `--mesh-prefix`  | `/workspace/bebop_bot/ros2/src/bebopv2_description/meshes` |

The script relies on `xacro` (declared in `package.xml`) and `python3`
(part of the base image), both available in `bebop_ros2` once the
overlay is sourced.

### Importing the URDF into Isaac Sim (URDF → USD)

Once `bebopv2.urdf` is regenerated, convert it to USD **headlessly**
inside the Isaac Lab container — one command:

```sh
just lab-urdf-to-usd
```

This runs [`sim/scripts/urdf_to_usd_bebopv2.py`](../sim/scripts/urdf_to_usd_bebopv2.py)
via `isaaclab.sh -p`, which:

1. converts the URDF with Isaac Lab's `UrdfConverter` (the same importer
   the GUI uses) into the layered asset at `sim/usd/bebopv2/`
   (`bebopv2.usda` + `payloads/`), **deleting the previous generated
   asset first** — it's recoverable from git;
2. applies the post-import fixes from
   [`sim/scripts/post_import_bebopv2.py`](../sim/scripts/post_import_bebopv2.py)
   (see "Post-import fixup" below) directly to the USD root layer; and
3. prints a sanity report: joint completeness, per-link masses, and the
   measured sole height vs. the configured spawn lift (`LIFT_Z`) — it
   warns if a feet/leg redesign has made the spawn height stale.

The importer settings match the GUI table below
(`collision_from_visuals=False`, `self_collision=False`,
`merge_mesh=False`, floating base). After it finishes, verify with
`just lab-play --num_envs 1` — the env's joint-order assertion
(`preserve_order=True` in the action/observation terms) fails fast if
the re-import shuffled joints.

#### GUI flow (manual fallback)

If you need the GUI instead (e.g. debugging an importer issue), launch
Isaac Sim from the lab container (`/workspace/isaaclab/isaaclab.sh -s`):

1. `just lab-up && just lab-shell`
2. Launch Isaac Sim: `/workspace/isaaclab/isaaclab.sh -s`
3. In the Isaac Sim UI: **File → Import**, pick the URDF importer, and
   point it at
   `/workspace/bebop_bot/ros2/src/bebopv2_description/urdf/bebopv2.urdf`.
4. Configure the importer panel — see settings below.
5. Click **Import**. The importer writes USD into `USD Output` and
   creates `/World/bebopv2` (or `/bebopv2`) on the stage.
6. Run the post-import fixup script — see below.

#### URDF importer settings

Use exactly these values in the URDF importer panel:

| Section | Field | Value |
|---|---|---|
| Model | USD Output | `/workspace/bebop_bot/sim/usd/` |
| Model | ROS Package List | *(leave empty — no rows)* |
| Colliders | Collision From Visuals | unchecked |
| Colliders | Allow Self-Collision | unchecked |
| Options | Merge Mesh | unchecked |
| Options | Debug Mode | unchecked |

Notes:

- **USD Output** points at the bind-mounted `sim/usd/` directory in
  this repo, so the generated USD lands directly under version control
  (i.e. `sim/usd/bebopv2/`). The previous import is recoverable from
  git history — the headless pipeline deletes and regenerates that
  directory on every run.
- **ROS Package List** stays empty because the URDF uses absolute
  `file://` mesh paths (see "URDF mesh paths" above) — there are no
  `package://` URIs that need resolving.
- **Collision From Visuals** stays off because the URDF already
  declares explicit `<collision>` geometry per link; we don't want the
  importer to also generate convex hulls from the visual meshes.
- **Allow Self-Collision** stays off; we'll enable it only on links
  that need it (in the post-import fixup or in the Isaac Lab env), to
  avoid spurious foot ↔ shin contacts that wreck training.
- **Merge Mesh** stays off so each link keeps its own mesh prim — that
  preserves the URDF's joint structure 1:1, which the policy and
  `robot_state_publisher` both depend on.

#### Post-import fixup

The URDF importer leaves the asset in states that need fixing
for a free-standing biped:

- it may add a **fixed root joint** that anchors `base_link` to world
  (we want a free-floating base so PhysX simulates gravity);
- the robot prim sits at world origin, but `base_link`'s frame is at
  the **hip**, so half the robot spawns through the floor;
- there's no **IMU sensor** on `base_link`, but the on-robot stack and
  the trained policy both consume `/imu/data` (orientation, angular
  velocity, linear acceleration of the base frame);
- the foot rigid bodies lack `PhysxContactReportAPI`, which Isaac Lab's
  `ContactSensor` needs to surface ground-contact events.

[`sim/scripts/post_import_bebopv2.py`](../sim/scripts/post_import_bebopv2.py)
applies the fixes (idempotent — safe to re-run):

1. disable the root joint (if the importer added one),
2. ensure `base_link` is dynamic (not kinematic),
3. translate the robot up by `LIFT_Z` so the feet land on the ground
   plane — currently **0.765 m**: the sole sits 0.7302 m below
   `base_link` at zero pose (Jul 2026 feet) + 35 mm settle clearance.
   The headless converter re-measures this on every run and warns if a
   redesign makes it stale,
4. attach a 200 Hz IMU prim (`Imu_Sensor`) under
   `<robot>/Geometry/base_link`, and
5. bake `PhysxContactReportAPI` onto both foot prims.

The headless pipeline (`just lab-urdf-to-usd`) runs this automatically.
For the GUI flow: open **Window → Script Editor**, paste the file's
contents (or use **Open** and point it at
`/workspace/bebop_bot/sim/scripts/post_import_bebopv2.py`), and hit
**Run**. Then press **Play** — the robot should fall under gravity onto
the ground plane.

## Common commands

From the repo root:

```sh
just sim-up         # bring up isaac_sim + bebop_ros2 (profile: sim)
just lab-up         # bring up isaac_lab + bebop_ros2 (profile: lab)
just sim-down       # tear down sim profile
just lab-down       # tear down lab profile
just ros2-build     # rebuild only the bebop_ros2 image
just ros2-shell     # interactive shell in the running bebop_ros2
```

Inside the container — when you `exec` in (e.g. via `just ros2-shell`),
you land in a fresh shell that does **not** have ROS or the workspace
overlay sourced. Run these three commands first, every time, before
doing any ROS work:

```sh
source /ros_ws_entrypoint.sh   # sources /opt/ros/jazzy + bootstraps micro-ROS
colcon build                   # build (or rebuild) the workspace
source install/setup.bash      # overlay the freshly built workspace
```

After that the workspace is sourced and you can run ROS commands:

```sh
ros2 launch bebop_pilot ...
ros2 topic list
```

## Development workflow

End-to-end loop when working with real Teensy hardware:

```sh
# 1. Build + flash the locomotion firmware on the host (PlatformIO).
just fw-build           # firmware/bebop-locomotion env=ros
just fw-flash

# 2. Bring up the dev containers. First run takes ~2 minutes because the
#    entrypoint clones and builds the micro-ROS agent (see below).
just lab-up             # or just sim-up

# 3. Open an interactive shell in the running ros2 container.
just ros2-shell

# 4. Inside the container — bootstrap the env, build, and overlay.
source /ros_ws_entrypoint.sh
colcon build
source install/setup.bash

# 5. Now you can launch / inspect.
ros2 launch bebop_pilot bringup.launch.py
ros2 topic echo /joint_states

# 6. (Optional) Tail the Teensy debug serial from the host.
cat /dev/ttyACM1
```

`/dev` is bind-mounted into the container, so `/dev/ttyACM*` shows up
inside without any extra config — adding/removing the Teensy while the
container is running works.

## Working with the robot in RViz

`bebopv2_description` ships a ready-made launch file that brings up
`robot_state_publisher`, `joint_state_publisher_gui`, and `rviz2`
preloaded with `config/display.rviz` — i.e. a one-liner to view and
manually pose the robot.

X11 is already wired into the `bebop_ros2` container in
`docker-compose.yml` (`DISPLAY` env + `/tmp/.X11-unix` bind-mount), so
RViz windows render on your host display.

### One-time host setup

```sh
xhost +local:docker        # allow the container to talk to your X server
```

(You only need to do this once per login session, or until you reboot.)

### Launch

From the repo root:

```sh
just lab-up                # or `just sim-up` — brings up bebop_ros2
just ros2-shell            # exec into the container
```

Then **inside the container**:

```sh
source /ros_ws_entrypoint.sh
colcon build
source install/setup.bash

ros2 launch bebopv2_description display.launch.py
```

You should get:

- An **RViz** window with the robot model loaded and TF visualized.
- A **`joint_state_publisher_gui`** window with a slider per joint —
  drag the sliders to manually pose the robot in real time.

### Useful flags

- Hide the slider GUI and use a plain `joint_state_publisher` (joints
  default to zero):

  ```sh
  ros2 launch bebopv2_description display.launch.py gui:=false
  ```

- View **live** joint angles from the Teensy instead of slider input —
  start the micro-ROS agent against `/dev/ttyACM0` (see "micro-ROS
  agent" below) in one shell, and `display.launch.py gui:=false` in
  another. `robot_state_publisher` will TF the live `/joint_states` into
  RViz so the model mirrors the real robot.

### Troubleshooting

- `Could not connect to display` / `Authorization required` → run
  `xhost +local:docker` on the host (above).
- `rviz2: command not found` inside the container → you skipped
  `source /ros_ws_entrypoint.sh`. ROS isn't on `PATH` in a fresh
  `exec`'d shell until that runs.
- Robot shows in the TF tree but **meshes are missing / blank** → the
  URDF references absolute container paths under
  `/workspace/bebop_bot/ros2/...` (see "URDF mesh paths"). Make sure
  that bind-mount actually exists in the running container.

## micro-ROS agent

The `bebop_ros2` container bootstraps and hosts the micro-ROS agent
automatically. `docker/entrypoint.sh` does this on first run:

1. Clones [`micro_ros_setup`](https://github.com/micro-ROS/micro-ROS/tree/main/utility/micro_ros_setup)
   (Jazzy branch) into `src/micro_ros_setup/`.
2. Runs `rosdep update && rosdep install --from-paths src --ignore-src -y`.
3. `colcon build --packages-select micro_ros_setup --symlink-install`.
4. `ros2 run micro_ros_setup create_agent_ws.sh` (creates `src/uros/`).
5. `ros2 run micro_ros_setup build_agent.sh` (~2 minutes; populates
   `install/micro_ros_agent/`).

Both `src/micro_ros_setup/` and `src/uros/` are gitignored — they're
regenerated whenever a fresh container starts and the host paths are
empty.

After bootstrap, run the agent against the Teensy:

```sh
# Inside the container:
ros2 run micro_ros_agent micro_ros_agent serial \
    --dev /dev/ttyACM0 --baudrate 115200
```

### Re-bootstrapping by hand

If the entrypoint's heuristic ever bails out (e.g. you partially deleted
something), do it manually:

```sh
cd "$ROS_WS"
rm -rf src/micro_ros_setup src/uros build install log

git clone -b jazzy \
    https://github.com/micro-ROS/micro_ros_setup.git src/micro_ros_setup
sudo rosdep update
sudo rosdep install --from-paths src --ignore-src -y
colcon build --packages-select micro_ros_setup --symlink-install
source install/setup.bash

ros2 run micro_ros_setup create_agent_ws.sh
ros2 run micro_ros_setup build_agent.sh
source install/setup.bash
```

## Troubleshooting

### Container can't see the Teensy

```sh
ls /dev/ttyACM*        # on the host AND inside the container
```

If it shows on the host but not in the container, the `/dev` bind-mount
likely failed — `docker compose down && just lab-up` again. The compose
file already grants the right `device_cgroup_rules` for `ttyACM*`
(major 166).

### Agent starts but the Teensy doesn't connect

- Confirm the Teensy is on `/dev/ttyACM0` and the firmware is the
  `[env:ros]` build (the `[env:sim]` build talks micro-ROS to Isaac, not
  to the agent).
- The Teensy retries the agent handshake for ~50 seconds at boot;
  status LED blinks while waiting.
- Tail debug output: `cat /dev/ttyACM1` (or `pio device monitor --port /dev/ttyACM1`
  on the host).

### `ros2 node list` doesn't show the firmware node

- Confirm the agent is actually running: `pgrep -a micro_ros_agent` inside
  the container.
- Confirm `ROS_DOMAIN_ID` matches across host, container, and Teensy
  build (the container exports `ROS_DOMAIN_ID=0`; the Teensy build's
  default needs to match).

### `colcon build` complains about already-built micro-ROS

The micro-ROS agent build artifacts live in `install/micro_ros_agent/`.
A clean rebuild is just `rm -rf build install log && colcon build`.

## See also

- [`firmware/bebop-locomotion/README.md`](../firmware/bebop-locomotion/README.md)
  — the Teensy-side firmware (PlatformIO, `[env:sim]` and `[env:ros]`).
- [`firmware/bebop-linux/README.md`](../firmware/bebop-linux/README.md) —
  the Linux/SocketCAN alternative that runs on the Jetson directly.
- [`sim/README.md`](../sim/README.md) — Isaac Sim / Lab side; pairs with
  the `[env:sim]` firmware build for hardware-in-the-loop training.

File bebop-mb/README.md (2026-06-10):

# Bebop Motherboard (`bebop-mb`)

KiCad 10 project for the **Bebop Connector / motherboard** board. It is the interconnect
between an **NVIDIA Jetson Orin Nano** carrier board, a **Teensy 4.1** microcontroller, a
**Bosch BNO085 9‑DoF IMU** (Adafruit breakout), and a **CAN bus** front end. The board mostly
provides headers/breakouts and routes shared buses between these modules.

> Silkscreen title block: *"Bebop Connector"*.

## Schematic sheets

| Sheet file | Contents |
|---|---|
| `bebop-mb.kicad_sch` | Root sheet: BNO085 IMU header (`J8`) + IMU breakouts (`J11`/`J12`), CAN connectors (`J1`–`J4`), mounting holes, power |
| `teensy-mcu.kicad_sch` | Teensy 4.1 (`U1`) and its two breakout headers (`J6`/`J7`) |
| `jetson-interface.kicad_sch` | Jetson 40‑pin IDC header (`J5`) and its two breakout headers (`J9`/`J10`) |
| `can-transceiver.kicad_sch` | SN65HVD230 CAN transceiver (`U2`) + decoupling (`C14`) |

## Component / connector reference

| Ref | Part / type | Footprint | Purpose |
|---|---|---|---|
| `U1` | Teensy 4.1 (48‑pin THT, 2×24) | `bebop-mb:Teensy41_Simple` | Main MCU |
| `J6` | 1×24 socket | `PinSocket_1x24` | Teensy left row breakout (Teensy pins 1–24) |
| `J7` | 1×24 socket | `PinSocket_1x24` | Teensy right row breakout (Teensy pins 25–48) |
| `J5` | 2×20 IDC box header | `Connector_IDC:IDC-Header_2x20_P2.54mm_Vertical` | Ribbon to Jetson 40‑pin header |
| `J9` | 1×20 socket | `PinSocket_1x20` | Jetson **odd** pins (1,3,…,39) breakout |
| `J10` | 1×20 socket | `PinSocket_1x20` | Jetson **even** pins (2,4,…,40) breakout |
| `J8` | BNO085 breakout header (2×6) | `bebop-mb:BNO08x_Breakout` | Adafruit BNO085 IMU |
| `J11` | 1×6 socket | `PinSocket_1x6` | BNO085 primary‑pin breakout (VIN/3Vo/GND/SCL/SDA/INT) |
| `J12` | 1×6 socket | `PinSocket_1x6` | BNO085 secondary‑pin breakout (BT/P0/P1/RST/DI/CS) |
| `U2` | SN65HVD230 (SOIC‑8) | — | 3.3 V CAN transceiver |
| `C14` | 100 nF | `C_0603` | `U2` decoupling |
| `J1` | 3‑pin screw terminal | `TerminalBlock_Xinya XY308 3P` | CAN bus (CANH/CANL/GND) |
| `J2`,`J3`,`J4` | JST‑GH 2‑pin | `JST_GH_SM02B-GHS-TB` | CAN bus daisy‑chain (CANH/CANL) |
| `H1`–`H4` | M3 mounting holes | `MountingHole_3.2mm_M3` | Mechanical |

## Power rails

| Net | Notes |
|---|---|
| `+3.3V` | Main logic rail. Feeds BNO085 `VIN`, CAN transceiver `U2`, and the BNO `P0`/`P1` mode straps |
| `GND` | Common ground |
| `Vin` | Teensy `Vin` (broken out on `J7` pin 1) |

The Jetson 40‑pin header also exposes its own `3.3V` (pins 1, 17) and `5.0V` (pins 2, 4) on
`J9`/`J10`; these are **not** tied to the board `+3.3V` rail unless you bridge them.

---

## Teensy 4.1 (`U1`) → breakouts `J6` / `J7`

`J6`/`J7` are 1×24 socket breakouts; **`J6` pad N = Teensy pin N**, **`J7` pad N = Teensy pin N+24**.
Silkscreen on `J6`/`J7` shows the Teensy pin name.

### Active Teensy connections

| Function | Teensy pin (GPIO) | Breakout | Net |
|---|---|---|---|
| IMU SPI clock | 13 (SCK/LED) | `J7` pad 14 | `IMU_SCK` |
| IMU SPI MISO | 12 | `J6` pad 14 | `IMU_MISO` |
| IMU SPI MOSI | 11 | `J6` pad 13 | `IMU_MOSI` |
| IMU SPI CS | 10 | `J6` pad 12 | `IMU_CS` |
| IMU interrupt | 37 | `J7` pad 20 | `IMU_INT` |
| IMU reset | 36 | `J7` pad 21 | `IMU_RST` |
| CAN1 TX (CTX1) | 22 | `J7` pad 5 | `CAN1_TX` |
| CAN1 RX (CRX1) | 23 | `J7` pad 4 | `CAN1_RX` |
| I²C SCL (spare) | 19 (A5/SCL) | `J7` pad 8 | `IMU_SCL` |
| I²C SDA (spare) | 18 (A4/SDA) | `J7` pad 9 | `IMU_SDA` |

> `IMU_SCL`/`IMU_SDA` are the legacy I²C pins. The IMU was migrated to **SPI**, so these are
> now just an unused I²C bus broken out on `J7`.

---

## BNO085 IMU (`J8`) — wired for SPI

The BNO085 is configured for **SPI** (not I²C). Protocol is selected by tying `P0`/`P1` high.

| `J8` pin | BNO pad | SPI role | Net |
|---|---|---|---|
| 1 | VIN | power | `+3.3V` |
| 3 | GND | ground | `GND` |
| 4 | SCL | SCK (clock) | `IMU_SCK` |
| 5 | SDA | MISO (sensor → host) | `IMU_MISO` |
| 11 | DI | MOSI (host → sensor) | `IMU_MOSI` |
| 12 | CS | chip select | `IMU_CS` |
| 6 | INT | data‑ready | `IMU_INT` |
| 10 | RST | reset | `IMU_RST` |
| 8 | P0 (PS0) | mode select → **high** | `+3.3V` |
| 9 | P1 (PS1) | mode select → **high** | `+3.3V` |
| 2 | 3Vo | BNO 3.3 V out (breakout only) | — |
| 7 | BT | boot (breakout only) | `J12` pin 1 |

`J11` breaks out the primary row (VIN/3Vo/GND/SCL/SDA/INT) and `J12` the secondary row
(BT/P0/P1/RST/DI/CS); both simply follow whatever `J8` carries.

---

## Shared IMU SPI bus (Teensy **and** Jetson)

The BNO085 SPI bus is wired **in parallel** to both the Teensy and the Jetson so either can act
as master. They must **not** be active at the same time.

```
            IMU_SCK / IMU_MISO / IMU_MOSI / IMU_CS / IMU_INT / IMU_RST
                                  |
        +---------------+---------+---------+----------------+
        |               |                   |                |
   BNO085 (J8)     Teensy U1           Jetson J5         Breakouts
                (13/12/11/10,        (SPI0 + GPIO,      (J6/J7, J9/J10,
                 37/36)               see below)         J11/J12)
```

| Signal | BNO085 | Teensy 4.1 | Jetson 40‑pin |
|---|---|---|---|
| SCK | SCL | GPIO13 | pin 23 (SPI0_SCK) |
| MISO | SDA | GPIO12 | pin 21 (SPI0_MISO) |
| MOSI | DI | GPIO11 | pin 19 (SPI0_MOSI) |
| CS | CS | GPIO10 | pin 24 (SPI0_CS0\*) |
| INT | INT | GPIO37 | pin 7 (GPIO09) |
| RST | RST | GPIO36 | pin 15 (GPIO12) |

> ⚠️ **Bus contention:** there is no hardware isolation (no mux/buffer) between the two masters.
> Firmware must keep the **inactive** master's SCK/MOSI/CS (and INT/RST) pins as **high‑impedance
> inputs** so the two masters never drive the bus simultaneously.

---

## Jetson 40‑pin header (`J5`) → breakouts `J9` / `J10`

`J5` is a 2×20 IDC box header (ribbon to the Jetson carrier 40‑pin expansion header).
`J9` breaks out the **odd** column, `J10` the **even** column. Silkscreen on `J9`/`J10` is
`<Jetson pin #> <signal>`.

| Pin | Signal | | Pin | Signal |
|---:|---|---|---:|---|
| 1 | 3.3V | | 2 | 5.0V |
| 3 | I2C1_SDA | | 4 | 5.0V |
| 5 | I2C1_SCL | | 6 | GND |
| 7 | GPIO09 → **IMU_INT** | | 8 | UART1_TXD |
| 9 | GND | | 10 | UART1_RXD |
| 11 | UART1_RTS\* | | 12 | I2S0_SCLK |
| 13 | SPI1_SCK | | 14 | GND |
| 15 | GPIO12 → **IMU_RST** | | 16 | SPI1_CS1\* |
| 17 | 3.3V | | 18 | SPI1_CS0\* |
| 19 | SPI0_MOSI → **IMU_MOSI** | | 20 | GND |
| 21 | SPI0_MISO → **IMU_MISO** | | 22 | SPI1_MISO |
| 23 | SPI0_SCK → **IMU_SCK** | | 24 | SPI0_CS0\* → **IMU_CS** |
| 25 | GND | | 26 | SPI0_CS1\* |
| 27 | I2C0_SDA | | 28 | I2C0_SCL |
| 29 | GPIO01 | | 30 | GND |
| 31 | GPIO11 | | 32 | GPIO07 |
| 33 | GPIO13 | | 34 | GND |
| 35 | I2S0_FS | | 36 | UART1_CTS\* |
| 37 | SPI1_MOSI | | 38 | I2S0_DIN |
| 39 | GND | | 40 | I2S0_DOUT |

Pins in **bold** are routed to the shared IMU bus; all other pins are simply broken out on
`J9`/`J10` for access.

---

## CAN bus (`U2` + `J1`–`J4`)

`U2` (SN65HVD230, 3.3 V) bridges the Teensy CAN1 controller to the physical bus.

| `U2` side | Connects to |
|---|---|
| `D` (driver in) | `CAN1_TX` ← Teensy GPIO22 (CTX1) |
| `R` (receiver out) | `CAN1_RX` → Teensy GPIO23 (CRX1) |
| `CANH` / `CANL` | CAN connectors `J1`–`J4` |
| `VCC` / `GND` | `+3.3V` / `GND` |

- `J1` — 3‑pin screw terminal: **CANH / CANL / GND**.
- `J2`, `J3`, `J4` — JST‑GH 2‑pin: **CANH / CANL** (for daisy‑chaining nodes).

Add a 120 Ω termination resistor at the bus ends as needed (not currently populated on‑board).

---

## Notes

- This board is KiCad 10 (name‑based nets; no numbered net table).
- After editing any schematic sheet, run **Tools → Update PCB from Schematic** and re‑run **DRC**.
- The IMU SPI bus sharing relies on firmware discipline (see the contention warning above); if you
  want hardware‑guaranteed isolation, add series resistors or a GPIO/jumper‑selected SPI bus switch.

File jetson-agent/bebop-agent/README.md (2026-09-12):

# `bebop-agent`

On-device provisioning daemon that runs on every Bebop robot. Responsibilities:

- **Wi-Fi provisioning** (`src/wifi/`) — wraps `nmcli` / NetworkManager to
  scan, join, and report link status.
- **Hosted Network** (`src/ap.rs`) — hosts the `Bebop-XXXX` WPA2 hotspot
  while `mode = "ap"` (boot default) and tears it down for `mode = "client"`.
  No automatic fallback.
- **Mode button** (`src/button.rs`) — a GPIO press (default header
  pin 32 / `gpiochip0` line 41) toggles the mode
  between Hosted (`ap`) and Known (`client`) and persists it. Edit the
  Hosted SSID/password/band from the app.
- **Setup server** (`src/server.rs`) — protobuf-over-WebSocket on `:9091`
  (plus a status page) so the companion app can provision over the Hosted
  Network or the LAN.
- **Shared state** (`src/state.rs`) — cheap-to-clone handle passed between
  subsystems.

The agent no longer manages containers, OTA, or Bluetooth controllers; the
robot firmware (`firmware/bebop-linux`) runs natively and the app drives it
directly over the runtime WS.

## Building

```sh
cargo build --release -p bebop-agent
```

`protoc` must be on `PATH` (protobuf codegen). The binary is built natively
on arm64 — on the robot, an arm64 dev box, or in CI on `ubuntu-22.04-arm`
(artifact `bebop-agent-aarch64`).

## Running (dev)

```sh
BEBOP_AGENT_CONFIG=./deploy/examples/agent.toml \
RUST_LOG=info,bebop_agent=debug \
cargo run -p bebop-agent
```

The agent expects NetworkManager (`nmcli`) to be available. Raising the
Hosting the network requires root.

## Configuration

See [`../deploy/examples/agent.toml`](../deploy/examples/agent.toml). The
key knobs are `[network] mode` (`ap` / `client`, button-owned) and
`ap_ssid` / `ap_password` / `ap_band` for the Hosted Network. The mode
button is under `[network] button_*` (default pin 32 / `gpiochip0` line 41).

## Packaging / Install

See [`../deploy/`](../deploy/) for the systemd unit and install script.

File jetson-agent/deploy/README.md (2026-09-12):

# Deploy

Artifacts for shipping `bebop-agent` onto a Jetson.

| File | Purpose |
|---|---|
| `systemd/bebop-agent.service` | systemd unit that starts the agent on boot. |
| `scripts/install.sh` | Copies binary, config, and enables the unit. |
| `scripts/uninstall.sh` | Removes the binary and unit (keeps state dir). |
| `examples/agent.toml` | Reference config (installed to `/etc/bebop/`). |
| `debian/` | Reserved for `.deb` packaging (TODO). |

## Typical flow

The agent is built natively on arm64 now (no `cross`/QEMU). Pick whichever
arm64 Linux build host is convenient — the robot itself, an arm64 dev box,
or grab the `bebop-agent-aarch64` artifact from CI (built on
`ubuntu-22.04-arm`, see `.github/workflows/ci.yml`).

On an arm64 build box (from the repo root):

```sh
just build-jetson
# equivalent to:
# cd jetson-agent && cargo build --release -p bebop-agent
```

Copy the binary and this `deploy/` tree to the Jetson (e.g. via `scp`,
Ansible, or bake into your golden image), then on the Jetson:

```sh
sudo ./deploy/scripts/install.sh ./target/release/bebop-agent
```

The `just deploy user@robot.local` recipe at the repo root does this
end-to-end: scp the binary, rsync the deploy tree, run `install.sh` over
SSH.

## Prereqs on the Jetson

`install.sh` will (idempotently) install and enable what it can from the
distro repos:

- `network-manager` (the agent uses `nmcli` to scan/join Wi-Fi and to raise
  the Hosted Network)
- `dbus`

If your base image already has everything baked in, pass
`--skip-prereqs` to leave system packages alone:

```sh
sudo ./deploy/scripts/install.sh --skip-prereqs ./bebop-agent
```

## Debian packaging (TODO)

A `cargo-deb` recipe or a proper `debian/` directory will be added under
`debian/` so fleet rollouts can happen via `apt`.

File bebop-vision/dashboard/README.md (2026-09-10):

# bebop-vision ML review dashboard

The place ML engineers go to review the navd training dataset, hand-correct
teacher labels, and understand **why a trained model behaved the way it did**
on a recorded run.

The legacy inline-UI tool (`tools/dataset_dashboard.py`) was removed
2026-09-07. Its headless core lives on as `tools/dashboard_core.py` — the
single source of truth for npz/manifest/audit logic — wrapped by the
FastAPI backend (`tools/dashboard_api.py`).

## Layout

```
dashboard/                   this app (Vite + React 19 + TS + Tailwind 4)
tools/dashboard_api.py       FastAPI backend: dataset routes + model validation
tests/test_dashboard_api.py  HTTP contract tests (synthetic session tree)
```

## Run (dev)

Two processes:

```bash
# 1. API backend (port 8099; 9090-9092 are taken on the robot)
cd bebop-vision
python tools/dashboard_api.py --data datasets/navd-v0 --port 8099

# 2. Frontend dev server with HMR + /api proxy
cd bebop-vision/dashboard
npm install
npm run dev            # http://localhost:5173
```

## Run (production / robot)

Build once; the API server then serves the bundle as static files:

```bash
cd bebop-vision/dashboard
npm run build          # -> dashboard/dist/

cd bebop-vision
python tools/dashboard_api.py --host 0.0.0.0 --port 8099
# open http://<workstation>:8099
```

Install deps:

```bash
pip install -e "bebop-vision[dashboard]"     # fastapi/uvicorn/pydantic
```

For model validation, add onnxruntime — GPU build on NVIDIA workstations
(1.22.x = CUDA 12 build, matching the torch-shipped CUDA libs; the API
pre-loads them and falls back to CPU if unusable):

```bash
pip uninstall onnxruntime && pip install "onnxruntime-gpu==1.22.*"
```

## UI tour

**Sidebar (shared across tabs)** — session list with per-session
hand-review progress bars, a filter box, and the loaded-model status pill.

### Tick review

- **Toolbar**: tick navigation, jump filters (disagree / caution /
  unreviewed), the displayed grid (auto = hand-else-fused / hand / fused),
  mining-channel overlays, the SAM label overlay with alpha slider, and
  the SAM mask opacity slider.
- **SAM segmentation (step-3 artifact view)**: each color card (near +
  far) has an `off / sam / gate` selector.
  - `sam` — the raw SAM 3.1 floor mask from `sam_floor{,_far}/` in green.
  - `gate` — the SAM+depth per-pixel decision fuse_navd_labels.py applies:
    **green** = floor confirmed by the measured depth landing on the
    flat-ground prediction (became navigable), **red** = blocked evidence
    (off-ground surface or no depth at all), **transparent** =
    depth-consistent ground SAM missed (stays unconfirmed), sky, and the
    robot's own chassis. Gate needs the ray LUT + rig config; when they
    are unavailable only raw mode is offered.
  - Opacity is applied client-side (the slider never refetches); the card
    footer shows mask coverage and, in gate mode, navigable/blocked px.
- **Filmstrip**: every tick as a tiny class-balance bar (red/green/amber),
  with green top marks for hand-reviewed ticks and red marks for
  disagree ticks — scan a whole session at a glance and click to jump.
- **Media pane**: near color (with overlay), depth near, far color, depth far.
- **Editor pane**: camera-aligned 60×60 paint canvas with **projected
  image underlay** — the near/far camera image projected onto the grid
  through the ray LUT (each cell shows the mean color of the pixels whose
  flat-floor ray lands there; near camera wins, far fills the rest) — with
  a paint-opacity slider, brush-footprint preview, hover cell readout;
  class picker, brush size, undo / revert / save / clear-hand; stacked
  class-balance bars for fused vs hand; tick context (cmd_vel, odom, goal).
- Saving writes `hand` into `labels/<stamp>.npz` — additive, teacher keys
  never touched, every edit audited to `hand_edits.jsonl`.
- Full keyboard model: `←/→` nav · `1/2/3` classes · `[ ]` brush · `u` undo
  · `s` save · `r` revert · `t` grid source · `o` overlay · `d/c/n/f` jumps
  · `?` shortcuts modal.

### Pipeline (the artifact browser)

One live row per session across the seven pipeline stages: **record**
(raw MCAP in `datasets/sessions/`, size), **extract** (tick count +
manifest), **SAM** (mask counts + sampled mean coverage per camera),
**fuse** (`fused` labels per tick), **review** (hand edits) — click the
session name to open it in tick review. Below: the global **train +
export** artifacts (every `train_log.jsonl` under `runs/` and `weights/`
with epochs + best val_miou, the exported ONNX files with sizes, and the
torch checkpoint dirs) and a jump into model validation. Refresh rescans.

### Model validation (the "why" tab)

- Load any exported ONNX (default `weights/navd.onnx`). Inference runs on
  the CUDA execution provider when available (torch's bundled CUDA libs
  are pre-loaded; CPU is the automatic fallback), with a warmup pass at
  load so the first replay is instant.
- **Replay player**: press play and the session plays back tick-by-tick —
  every shown tick is run through the model with the EXACT runtime
  preprocessing path (`bebop_vision/navd_pre.py`) and scored against the
  effective teacher, **next to the camera views** (near/far color + depth,
  fetched light without the label grids). Transport: play/pause (space),
  skip (←/→), 0.5×/1×/2× speed, filmstrip scrubbing, worst-tick rows jump
  into the player. Then inspect:
  - model grid vs teacher/hand label
  - disagreement map colored by the model's class
  - per-class probability heatmaps (confidence, not just argmax)
  - the goal raster the model received
  - the `frac_navigable` gate verdict — rejected ticks still render, with
    the reason the drive node would hold (a rejection is exactly the
    behavior you're debugging).
- **Session sweep**: batch over every tick → mean agreement, confusion
  matrix, per-class IoU, runtime-rejected list, worst-ticks table (click a
  row to replay that tick). Persisted to `<session>/validation_<model>.json`
  so re-runs after a retrain are comparable.

## Stamps are strings

19-digit `stamp_ns` exceeds JS `Number.MAX_SAFE_INTEGER`; the client passes
`stamp` (20-digit zero-padded string, matches filenames) everywhere.

## Ports

Default 8099. Do NOT use 9090 (firmware), 9091 (bebop-agent), 9092
(bebop-vision videoserver).

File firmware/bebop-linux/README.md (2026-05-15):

# Bebop Linux Firmware

Linux-based firmware for the Bebop robot using SocketCAN and ONNX Runtime for neural network inference.

## Features

- **50 Hz control loop** (configurable up to 200+ Hz)
- **SocketCAN** for direct CAN bus communication
- **ONNX Runtime** for neural network policy inference
- **Robstride motor support** (RS01-RS04) with MIT-style impedance control
- **ODrive motor support** (S1) with velocity control
- **UDP command interface** for teleoperation
- **Safety checks** with IMU-based fall detection

## Architecture

```
┌─────────────────────────────────────────────────────────────┐
│                    Main Control Loop (50 Hz)                │
│  ┌──────────┐  ┌──────────┐  ┌──────────┐  ┌──────────┐   │
│  │   IMU    │→ │  Observe │→ │  Policy  │→ │ Commands │   │
│  └──────────┘  └──────────┘  └──────────┘  └──────────┘   │
│        ↑                          ↑              │          │
│        │                          │              ↓          │
│  ┌──────────┐              ┌──────────┐   ┌──────────┐    │
│  │   UDP    │              │   ONNX   │   │ SocketCAN│    │
│  │ Commands │              │  Model   │   │   Bus    │    │
│  └──────────┘              └──────────┘   └──────────┘    │
└─────────────────────────────────────────────────────────────┘
                                                  │
                    ┌─────────────────────────────┼─────────────────────────────┐
                    ↓                             ↓                             ↓
            ┌──────────────┐             ┌──────────────┐             ┌──────────────┐
            │  Robstride   │             │  Robstride   │             │   ODrive     │
            │  Hip Motor   │             │  Knee Motor  │             │   Wheel      │
            └──────────────┘             └──────────────┘             └──────────────┘
```

## Requirements

### System Requirements

- Linux (tested on Ubuntu 22.04+, Raspberry Pi OS, Jetson)
- Rust 1.70+ (install via [rustup](https://rustup.rs/))
- CAN bus interface (USB-CAN adapter, built-in CAN, etc.)
- ONNX Runtime 1.16+ (dynamically loaded)

### Hardware Setup

1. **CAN Interface**: Configure your CAN interface at 1 Mbps:

```bash
# Bring up can0 at 1 Mbps
sudo ip link set can0 type can bitrate 1000000
sudo ip link set can0 up

# Verify
ip link show can0
```

2. **ONNX Runtime**: Install ONNX Runtime:

```bash
# Download from https://github.com/microsoft/onnxruntime/releases
# Or install via package manager if available

# For aarch64 (Jetson, Raspberry Pi):
wget https://github.com/microsoft/onnxruntime/releases/download/v1.16.3/onnxruntime-linux-aarch64-1.16.3.tgz
tar xzf onnxruntime-linux-aarch64-1.16.3.tgz
export LD_LIBRARY_PATH=$LD_LIBRARY_PATH:$(pwd)/onnxruntime-linux-aarch64-1.16.3/lib

# For x86_64:
wget https://github.com/microsoft/onnxruntime/releases/download/v1.16.3/onnxruntime-linux-x64-1.16.3.tgz
```

## Building

```bash
# Debug build
cargo build

# Release build (optimized)
cargo build --release

# Run tests
cargo test
```

## Releasing & deploying to a Jetson

`bebop-linux` ships as a single tarball that bundles the aarch64 binary,
the joint config (`bebop_v2.yaml`), the ONNX policy (`policy.onnx` +
`policy.onnx.data`), and the systemd unit. The robot's runtime, config
and policy weights are always rolled forward together so a "good build"
on the Jetson is exactly the contents of one tarball.

### Cutting a release

```bash
# from a clean main checkout
git tag firmware/v0.2.0
git push origin firmware/v0.2.0
```

The `firmware-jetson` job in `.github/workflows/ci.yml` builds the
binary on `ubuntu-22.04-arm`, packs `bebop-linux-aarch64.tar.gz`
(`bin/`, `config/`, `systemd/`, `VERSION`) with a sibling `.sha256`,
and publishes both to a GitHub Release named after the tag.

### Installing on the Jetson

The `scripts/install-jetson.sh` installer fetches the latest matching
Release by default. From any reasonably fresh checkout on the robot:

```bash
sudo ./scripts/install-jetson.sh --linux-only
```

That one command installs the latest tagged firmware bundle, writes the
config and policy into `/etc/bebop/`, installs the systemd unit, and
enables + restarts `bebop-linux.service`.

For pinned or pre-release installs:

```bash
sudo ./scripts/install-jetson.sh --linux-only --release firmware/v0.2.0
sudo ./scripts/install-jetson.sh --linux-only --run-id N
```

For installing straight from a local checkout (no GitHub round-trip —
useful for on-device dev iteration):

```bash
# build first, then install the pre-built binary + working-tree configs
cargo build --release            # in firmware/bebop-linux/
sudo ./scripts/install-jetson.sh --linux-only --local

# or do both in one shot (cargo runs as your invoking user)
sudo ./scripts/install-jetson.sh --linux-only --local --build
```

It lays things down as:

```
/usr/local/bin/bebop-linux
/etc/bebop/bebop_v2.yaml          # overwritten; previous saved as .yaml.bak
/etc/bebop/policy.onnx            # graph
/etc/bebop/policy.onnx.data       # external-data weights (must travel with policy.onnx)
/etc/systemd/system/bebop-linux.service
```

The unit invokes `bebop-linux --config /etc/bebop/bebop_v2.yaml`, which
resolves `--policy` to `<config-dir>/policy.onnx` by default — so the
policy files just need to sit next to the YAML.

### Rolling back

Either re-run the installer pointing at the previous tag
(`--release firmware/v0.1.9`) or restore the saved YAML on its own:

```bash
sudo mv /etc/bebop/bebop_v2.yaml.bak /etc/bebop/bebop_v2.yaml
sudo systemctl restart bebop-linux
```

## Running

### Basic Usage

```bash
# Run with default settings
./target/release/bebop-linux --model model.onnx

# Specify CAN interface
./target/release/bebop-linux --model model.onnx --can can0

# Run at 100 Hz
./target/release/bebop-linux --model model.onnx --rate 100

# Simulation mode (no hardware)
./target/release/bebop-linux --sim

# Passthrough mode (no policy)
./target/release/bebop-linux --no-policy
```

### Command Line Options

| Option | Short | Default | Description |
|---|---|---|---|
| `--model` | `-m` | `model.onnx` | Path to ONNX policy file |
| `--can` | `-c` | `can0` | CAN interface name |
| `--port` | `-p` | `10000` | UDP command port |
| `--rate` | `-r` | `50` | Control loop rate (Hz) |
| `--no-policy` | | | Disable policy, passthrough mode |
| `--sim` | | | Simulation mode (no hardware) |
| `--help` | `-h` | | Print help |

### Environment Variables

```bash
# Set log level
export RUST_LOG=debug  # or info, warn, error

# Specify CAN interfaces
export CAN_INTERFACES=can0,can1,can2,can3
```

## UDP Command Protocol

Send JSON commands to UDP port 10000:

```json
// Velocity command
{"xvel": 0.5, "yvel": 0.0, "angvel": 0.1}

// Reset command
{"type": "reset"}
```

### Python Example

```python
import socket
import json

sock = socket.socket(socket.AF_INET, socket.SOCK_DGRAM)

# Send velocity command
cmd = {"xvel": 0.5, "yvel": 0.0, "angvel": 0.0}
sock.sendto(json.dumps(cmd).encode(), ("localhost", 10000))
```

## Converting Your Model to ONNX

If your policy is trained in PyTorch:

```python
import torch
import torch.onnx

# Load your trained policy
model = YourPolicy()
model.load_state_dict(torch.load("policy.pt"))
model.eval()

# Create dummy input matching observation size
dummy_input = torch.randn(1, 30)  # [batch, obs_dim]

# Export to ONNX
torch.onnx.export(
    model,
    dummy_input,
    "model.onnx",
    input_names=["obs"],
    output_names=["actions"],
    dynamic_axes={"obs": {0: "batch"}, "actions": {0: "batch"}},
    opset_version=14,
)
```

## Configuration

### Observation Format (must match training!)

| Index | Description | Scaling |
|---|---|---|
| 0-2 | Base linear velocity (x, y, z) | × SCALE_LIN_VEL |
| 3-5 | Base angular velocity (x, y, z) | × SCALE_ANG_VEL |
| 6-8 | Projected gravity | (no scaling) |
| 9-11 | Command velocity (vx, vy, wz) | × SCALE_LIN_VEL/ANG_VEL |
| 12-17 | Joint positions (relative to default) | × SCALE_DOF_POS |
| 18-23 | Joint velocities | × SCALE_DOF_VEL |
| 24-29 | Last action | (no scaling) |

### Motor Configuration

Edit `src/config.rs` to match your hardware:

```rust
JointConfig {
    name: "left_hip_pitch".to_string(),
    index: 0,
    can_id: 31,
    can_bus: "can0".to_string(),
    motor_type: MotorType::Robstride(RobstrideModel::RS04),
    default_position: 0.0,
    position_min: -0.8,
    position_max: 0.8,
    kp: 50.0,
    kd: 2.0,
},
```

## Comparison to Teensy Firmware

| Feature | Teensy | Linux |
|---|---|---|
| Control Rate | 200 Hz | 50-500 Hz |
| CAN Interface | FlexCAN_T4 | SocketCAN |
| Policy Inference | Embedded C++ | ONNX Runtime |
| ROS Integration | micro-ROS | Native ROS 2 (optional) |
| Development | PlatformIO | Cargo |
| Debug | Serial | Full Linux tooling |
| Multi-bus | 3 buses max | Unlimited (per hardware) |

## Troubleshooting

### CAN Bus Issues

```bash
# Check CAN interface status
ip -details link show can0

# Monitor CAN traffic
candump can0

# Check for bus errors
dmesg | grep can0
```

### Permission Issues

```bash
# Add user to dialout group (for USB-CAN adapters)
sudo usermod -a -G dialout $USER

# Or run with sudo (not recommended for production)
sudo ./target/release/bebop-linux
```

### ONNX Runtime Issues

```bash
# Set library path
export LD_LIBRARY_PATH=$LD_LIBRARY_PATH:/path/to/onnxruntime/lib

# Check if library is found
ldd target/release/bebop-linux | grep onnx
```

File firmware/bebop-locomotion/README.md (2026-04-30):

# Bebop Locomotion Firmware

Teensy 4.1 locomotion controller for the Bebop robot. Runs neural network policy inference on-board, interfaces with CAN motor controllers (ODrive, Robstride), and communicates with ROS2 via micro-ROS.

## Architecture

```
┌─────────────────────────────────────────────────────────────────┐
│                         Teensy 4.1                              │
│  ┌─────────────┐    ┌─────────────┐    ┌─────────────────────┐  │
│  │   Policy    │───▶│   Motor     │───▶│  CAN Bus            │  │
│  │  Inference  │    │  Commands   │    │  (ODrive/Robstride) │  │
│  └─────────────┘    └─────────────┘    └─────────────────────┘  │
│         ▲                                        │              │
│         │           ┌─────────────┐              │              │
│         └───────────│ Observation │◀─────────────┘              │
│                     │   Builder   │◀──── IMU (BNO085)           │
│                     └─────────────┘                             │
│                            │                                    │
│                     ┌──────▼──────┐                             │
│                     │  micro-ROS  │◀────── USB Serial           │
│                     └─────────────┘                             │
└─────────────────────────────────────────────────────────────────┘
```

## Build Modes

| Mode | Description | Entry Point |
|---|---|---|
| `sim` | **Isaac Sim HIL** - Policy on Teensy, sensor data from simulation via micro-ROS | `main_sim.cpp` |
| `ros` | **Hardware Mode** - Policy on Teensy, sensor data from real IMU/motors via CAN | `main.cpp` |

## Quick Start

```bash
cd firmware/bebop-locomotion

# Build (default: sim mode)
pio run

# Build for hardware
pio run -e ros

# Upload to Teensy
pio run --target upload

# Monitor debug output (SerialUSB1)
pio device monitor
```

## Motor Control

### Joint Mapping

| Index | Name | Motor Type | Control Mode |
|---|---|---|---|
| 0 | `left_hip_pitch` | Robstride | Position |
| 1 | `right_hip_pitch` | Robstride | Position |
| 2 | `left_knee_pitch` | Robstride | Position |
| 3 | `right_knee_pitch` | Robstride | Position |
| 4 | `left_wheel` | ODrive | Velocity |
| 5 | `right_wheel` | ODrive | Velocity |

### Serial Debug Commands

Connect to the debug serial port (`SerialUSB1`, 115200 baud):

```bash
# On Linux
screen /dev/ttyACM1 115200
# or
pio device monitor --port /dev/ttyACM1
```

| Command | Description |
|---|---|
| `help` | Show available commands |
| `pos` / `status` | Show all joint positions (rad & deg) |
| `zero <joint>` | Set current position as zero (Robstride joints 0-3 only) |
| `enable <joint\|all>` | Enable motor(s) |
| `disable <joint\|all>` | Disable motor(s) |

**Example:**
```
> pos
  Joint Status:
    [0] left_hip_pitch: OK pos=0.123 rad (7.0 deg)
    [1] right_hip_pitch: OK pos=-0.045 rad (-2.6 deg)
    ...

> zero 0
  Setting zero for joint 0 (left_hip_pitch)...
    1. Disabling motor...
    2. Setting mechanical zero...
    3. Saving to flash...
    4. Re-enabling motor...
  Done!

> enable all
  Enabled all motors
```

### ROS2 Motor Commands

Commands are sent via `/joint_commands` topic (`sensor_msgs/JointState`):

**Position/Velocity Control:**
- `position[]` - Target positions for leg joints (rad)
- `velocity[]` - Target velocities for wheel joints (rad/s)

**Special Commands (via `effort[]` field):**

| Value | Command | Description |
|---|---|---|
| `-999.0` | Clear Errors | Clear motor error flags |
| `-998.0` | Enable All | Enable all motors |
| `-997.0` | Disable All | Disable all motors |
| `-996.0` | Reset & Enable | Clear errors and enable |
| `-995.0` | Policy Mode | Switch to neural network control |
| `-994.0` | Manual Mode | Switch to passthrough/manual control |

**Example (Python):**
```python
from sensor_msgs.msg import JointState

# Send motor enable command
cmd = JointState()
cmd.effort = [-998.0]  # MOTOR_CMD_ENABLE_ALL
publisher.publish(cmd)

# Send position/velocity command
cmd = JointState()
cmd.name = ['left_hip_pitch', 'right_hip_pitch', 'left_knee_pitch', 
            'right_knee_pitch', 'left_wheel', 'right_wheel']
cmd.position = [0.0, 0.0, 0.5, 0.5, 0.0, 0.0]  # Leg positions
cmd.velocity = [0.0, 0.0, 0.0, 0.0, 5.0, 5.0]  # Wheel velocities
publisher.publish(cmd)
```

## ROS2 Topics

### Published Topics

| Topic | Type | Rate | Description |
|---|---|---|---|
| `/joint_states` | `sensor_msgs/JointState` | 100 Hz | Joint positions and velocities |
| `/imu/data` | `sensor_msgs/Imu` | 100 Hz | IMU orientation, angular velocity, acceleration |
| `/motor_temps` | `std_msgs/Float32MultiArray` | 10 Hz | Motor temperatures (see format below) |
| `/motor_status` | `std_msgs/Int32MultiArray` | 10 Hz | Motor error codes and states |

### Subscribed Topics

| Topic | Type | Description |
|---|---|---|
| `/joint_commands` | `sensor_msgs/JointState` | Motor position/velocity commands |
| `/cmd_vel` | `geometry_msgs/Twist` | Velocity commands for policy |

### Diagnostic Data Format

**`/motor_temps`** - `Float32MultiArray` with `NUM_JOINTS * 2` floats:
```
[motor0_temp, motor0_board_temp, motor1_temp, motor1_board_temp, ...]
```

**`/motor_status`** - `Int32MultiArray` with `NUM_JOINTS * 4` ints:
```
[motor0_error, motor0_state, motor0_enabled, motor0_extra, ...]
```
- `extra`: Bus voltage × 100 for ODrive, fault bits for Robstride

## Project Structure

```
bebop-locomotion/
├── include/
│   ├── BebopPolicy.h      # Auto-generated neural network weights
│   ├── BNO085_IMU.h       # IMU driver
│   ├── GenericMotor.h     # Motor interface abstraction
│   ├── MicroROS.h         # micro-ROS communication (sim mode)
│   ├── ODriveMotor.h      # ODrive CAN protocol
│   ├── RobotConfig.h      # Joint/motor configuration
│   ├── RobstrideMotor.h   # Robstride CAN protocol
│   ├── RosPublishers.h    # ROS topic publishers (ros mode)
│   └── SerialCommands.h   # Debug serial interface
├── src/
│   ├── main.cpp           # Hardware mode entry point
│   ├── main_sim.cpp       # Simulation mode entry point
│   ├── MicroROS.cpp       # micro-ROS implementation
│   ├── RosPublishers.cpp  # ROS publisher implementation
│   └── SerialCommands.cpp # Serial command parser
└── platformio.ini         # Build configuration
```

## Hardware Connections

### Teensy 4.1 Pinout

| Function | Pin |
|---|-----|
| CAN1 TX | 22 |
| CAN1 RX | 23 |
| IMU SCL | 19 |
| IMU SDA | 18 |
| IMU INT | 36 |
| IMU RST | 35 |
| Status LED | 13 |

### USB Ports

With `USB_DUAL_SERIAL` enabled:
- **USB0** (`Serial`) - micro-ROS agent communication
- **USB1** (`SerialUSB1`) - Debug output and serial commands

## Updating the Policy

Neural network weights are stored in `include/BebopPolicy.h`. To update:

```bash
# 1. Export from Isaac Lab
./isaaclab.sh -p bebop_training/export_bebop_model.py \
    --checkpoint training_logs/.../model_XXXX.pt \
    --headless

# 2. Copy to firmware
cp training_logs/.../BebopPolicy.h firmware/bebop-locomotion/include/

# 3. Rebuild and upload
cd firmware/bebop-locomotion
pio run --target upload
```

## IDE Setup (VSCode + clangd)

```bash
# Generate compilation database
cd firmware/bebop-locomotion
pio run -t compiledb
```

The repo includes `.clangd` at the root pointing to the firmware's `compile_commands.json`.

Ensure your VSCode settings include:
```json
{
    "clangd.arguments": [
        "--query-driver=**/*arm-none-eabi*",
        "--header-insertion=never"
    ]
}
```

Then restart clangd: `Ctrl+Shift+P` → `clangd: Restart language server`

## Troubleshooting

### Build fails with missing headers
```bash
pio run -t clean && pio run
```

### Upload fails
1. Press Teensy button for bootloader mode
2. Check connection: `ls /dev/ttyACM*`
3. Install udev rules (see below)

### Install udev rules (Linux)
```bash
curl -fsSL https://raw.githubusercontent.com/platformio/platformio-core/develop/platformio/assets/system/99-platformio-udev.rules | sudo tee /etc/udev/rules.d/99-platformio-udev.rules
sudo udevadm control --reload-rules && sudo udevadm trigger
```

## License

Part of the Bebop Robot project.

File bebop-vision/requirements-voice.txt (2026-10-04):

# Voice (speech-to-speech) service dependencies.
#
# Installed into a DEDICATED venv (`bebop-vision/.venv-voice`) by
# `scripts/install-jetson.sh --setup-voice`, not into the recorder's `.venv`:
# the recorder pins numpy 1.26.4 for pyorbbecsdk, and TensorRT Edge-LLM pulls
# its own numpy/CUDA stack. Keeping them separate avoids breaking the camera.
#
# `tensorrt-edgellm[server]` ships the high-level Python API, the
# OpenAI-compatible server (`tensorrt-edgellm-serve`), and Hugging Face Hub
# downloads. `server-tools` adds Transformers, which the checkpoint-direct
# builder needs to convert the tokenizer (without it the first serve fails:
# "tokenizer conversion requires the Transformers package").
#
# `tools` adds the quantization toolchain (PyTorch, NVIDIA ModelOpt, datasets,
# audio tooling). Qwen3-Omni is only supported at NVFP4 / INT4-AWQ, so the
# FP16 checkpoint downloaded from the Models page must be quantized once with
# `tensorrt-edgellm-quantize llm --quantization nvfp4` before serving. See
# docs/voice.md.
#
# The published aarch64 wheel covers Jetson Thor (JetPack 7.x, CUDA 13, SM110,
# platform TensorRT 10) — no source/CMake build.
tensorrt-edgellm[server,server-tools,tools]==0.11.0

# `datasets`/`sklearn` pull pandas, but with --system-site-packages pip treats
# JetPack's system pandas (built against numpy 1.x) as satisfied. The venv has
# numpy 2.2.6, so the quantizer then dies with
# "numpy.dtype size changed, may indicate binary incompatibility".
# Pin a venv-local pandas so the numpy-2 ABI wins.
pandas>=2.2

# The gateway talks to the local Edge-LLM server over HTTP/SSE and serves the
# app its own WebSocket. `uvicorn` (from [server]) needs one of these to speak
# WebSocket; `websockets` is the aarch64-friendly choice.
websockets>=12
httpx>=0.27

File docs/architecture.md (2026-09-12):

# Architecture

## Components

### `jetson-agent/bebop-agent` (Rust, systemd service)

The provisioning daemon. It owns first-time Wi-Fi setup and the Hosted Network
fallback; everything else on the robot runs as native binaries/venvs.

Subsystems (see `jetson-agent/bebop-agent/src/`):

- **`wifi/`** — wraps `nmcli` to scan/join Wi-Fi, and polls link status.
- **`ap.rs`** — Hosted Network supervisor. Hosts the `Bebop-XXXX` hotspot
  while `mode = "ap"` and tears it down for `mode = "client"`. No automatic
  fallback; the mode is a two-way switch.
- **`button.rs`** — the physical mode button (GPIO press) that toggles
  `ap` ⇄ `client` and persists the choice.
- **`server.rs`** — setup server: protobuf-over-WebSocket (`:9091`) plus a
  status page. Reachable on the LAN or over the Hosted Network.
- **`dispatcher.rs`** — maps `ClientRequest`s to Wi-Fi / config actions.
- **`state.rs`** — shared in-memory state (`Arc<Inner>` with async `RwLock`s).

See [`setup-protocol.md`](setup-protocol.md) for the wire protocol.

### `jetson-agent/bebop-proto` (Rust, shared crate)

Protobuf schema for the setup protocol, compiled with `prost-build` into
Rust types used by the agent. The companion app generates TypeScript
bindings from the same `.proto` via `npm run gen-proto`.

### `firmware/bebop-linux` (Rust, systemd service)

The robot firmware: SocketCAN + ODRIVE/Robstride control loop, safety
supervisor, IMU, and the runtime WebSocket API (`:9090`) the operator app
drives through. Runs as a native binary (`bebop-linux.service`). The vision
stack runs from a Python venv (`bebop-vision/`) and serves MJPEG on `:9092`.

The firmware also owns start/stop control of the vision stack: it drives the
`bebop-vision.service` systemd unit (`systemctl start/stop`) and reflects the
unit's state in telemetry (`VisionState`). The operator app's Teleop screen
has the Start/Stop vision button. The unit is installed by
`scripts/install-jetson.sh` but **not enabled** — it stays stopped until the
operator starts it, and its own sandbox (venv, Orbbec `/dev` nodes, `/tmp`
lock) is intentionally separate from `bebop-linux.service`'s.
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

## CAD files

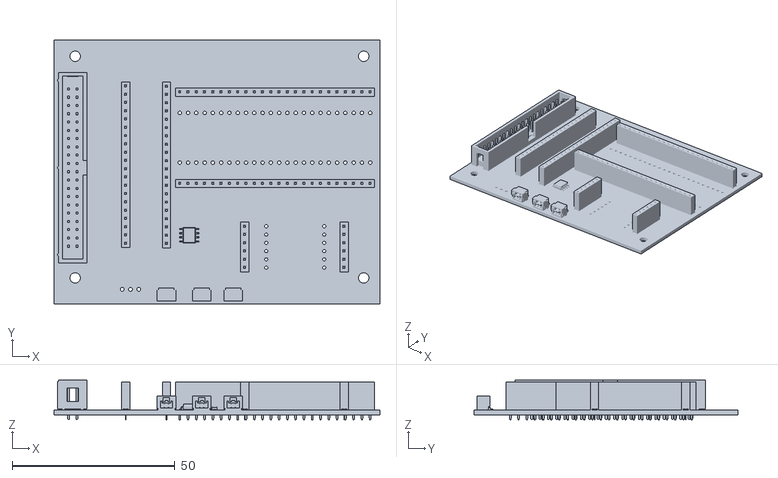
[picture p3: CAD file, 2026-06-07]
bebop-mb/bebop-mb.stl
100.0 x 81.0 x 12.2

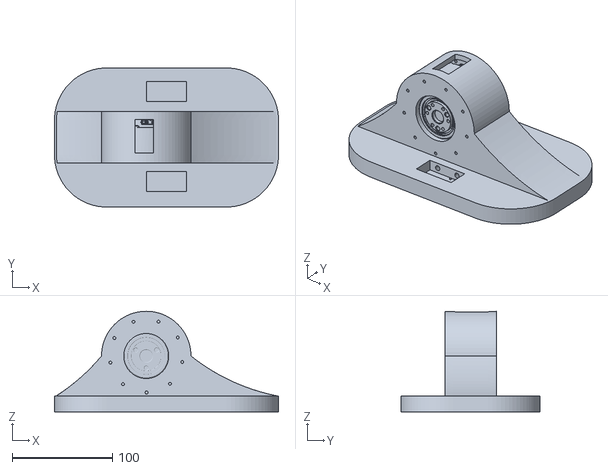
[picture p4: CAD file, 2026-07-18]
ros2/src/bebopv2_description/meshes/foot_right_1.stl
224.0 x 139.0 x 100.5

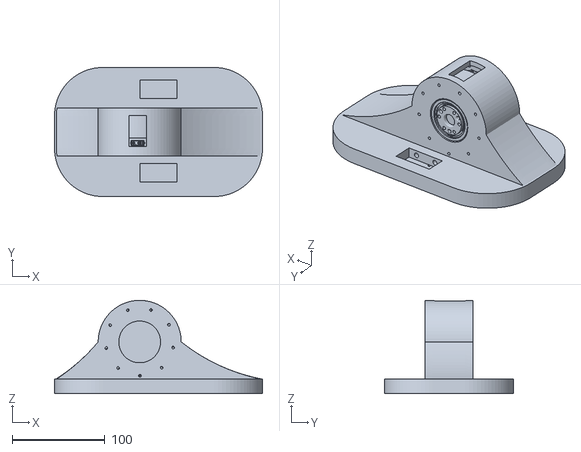
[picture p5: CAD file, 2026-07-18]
ros2/src/bebopv2_description/meshes/foot_left_1.stl
224.0 x 139.0 x 100.5

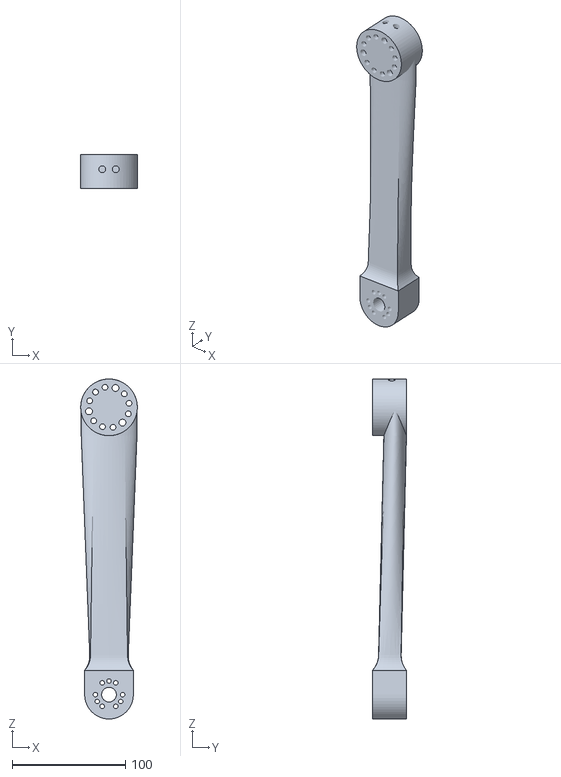
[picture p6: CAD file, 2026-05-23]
ros2/src/bebopv2_description/meshes/knee_flexion_left_1.stl
50.0 x 30.0 x 300.0

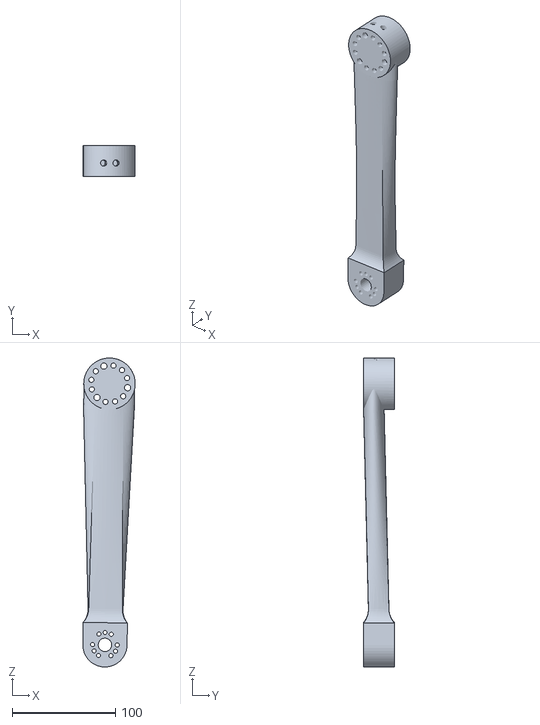
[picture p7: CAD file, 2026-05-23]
ros2/src/bebopv2_description/meshes/knee_flexion_right_1.stl
50.9 x 30.0 x 300.0

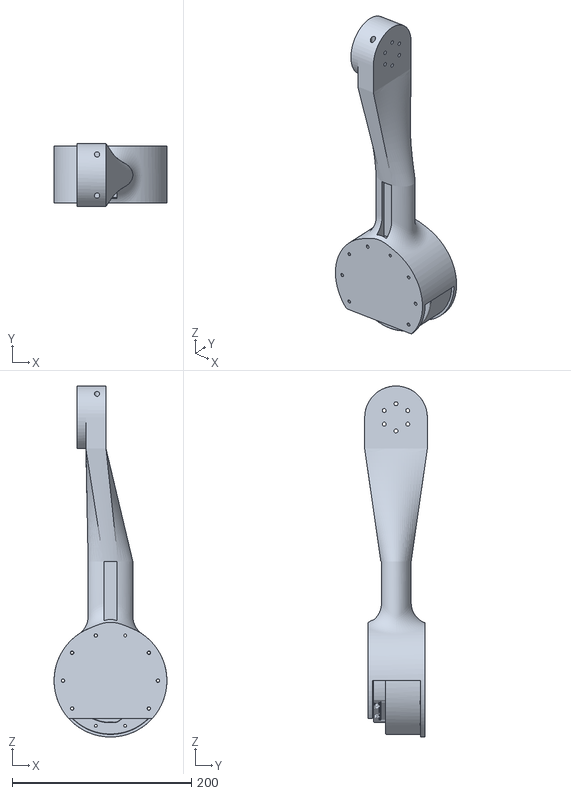
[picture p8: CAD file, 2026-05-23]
ros2/src/bebopv2_description/meshes/hip_abduction_left_1.stl
126.0 x 70.0 x 392.0

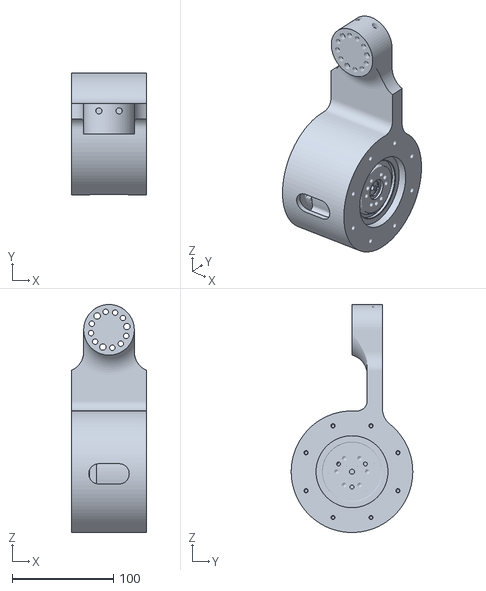
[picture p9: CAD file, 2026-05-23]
ros2/src/bebopv2_description/meshes/hip_flexion_left_1.stl
74.1 x 120.0 x 225.0

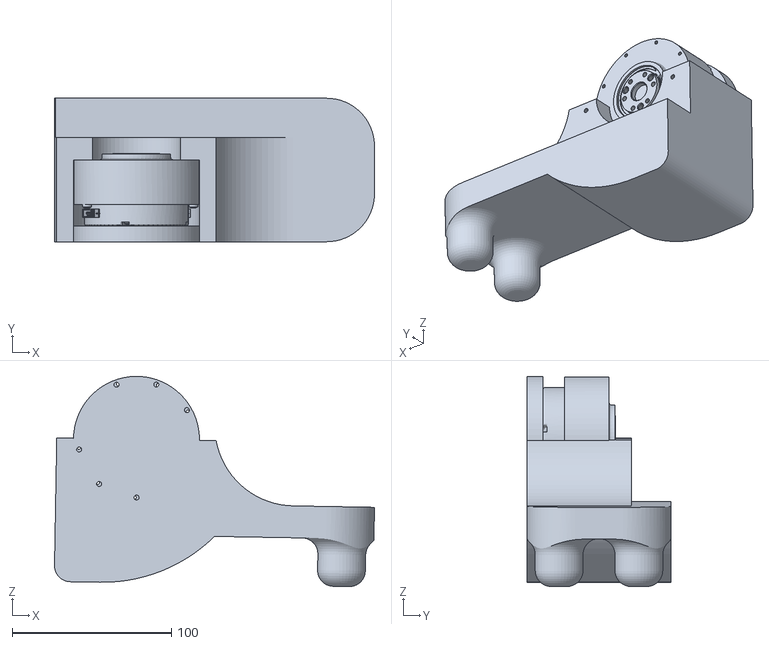
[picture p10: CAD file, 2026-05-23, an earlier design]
ros2/src/bebopv2_description.old/meshes/foot_left_1.stl
200.7 x 90.0 x 131.8

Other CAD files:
ros2/src/bebopv2_description/meshes/hip_abduction_right_1.stl
ros2/src/bebopv2_description/meshes/hip_flexion_right_1.stl
ros2/src/bebopv2_description.old/meshes/hip_flexion_right_1.stl
ros2/src/bebopv2_description.old/meshes/hip_abduction_right_1.stl
ros2/src/bebopv2_description.old/meshes/foot_right_1.stl

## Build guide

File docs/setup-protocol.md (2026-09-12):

# Setup Protocol

How the companion app (`bebop-app`) provisions a robot via `bebop-agent`'s
setup server, and how the physical mode button works.

## Network modes

The robot has exactly two network modes, switched **only** by the physical
button press. There is no automatic fallback.

| Mode | Name | Behaviour |
|---|---|---|
| `ap` | Hosted Network | Hosts the `Bebop-XXXX` hotspot continuously (boot default). |
| `client` | Known Network  | Joins a saved Wi-Fi network; never hosts. |

Because the Wi-Fi radio is single-ended, switching modes drops the previous
link. A fresh robot boots into Hosted Network so it is reachable at
`192.168.42.1:9091` out of the box.

## Mode button

A momentary switch from a GPIO header pin to 3.3 V. A **press** (debounced)
toggles the mode and persists it to `/etc/bebop/agent.toml`. Set
`button_hold_secs > 0` to require a hold instead of a press.

- Default pin: Orin Nano header **pin 32** = `gpiochip0` line **41**
  (`GPIO07`). It has an internal pull-down in the pinmux, so wire the
  switch from the pin to **3.3 V** (header pins 1/17) — no resistor needed
  — and leave `button_active_low = false`. Avoid pins 7 and 15 (IMU
  INT/RST), and pin 29 (no internal pull; it floats).
- The agent requests the line via the pure-Rust `gpiocdev` crate (GPIO
  uAPI v2). The Jetson pinmux fixes each pin's idle bias (a runtime bias
  request is effectively cosmetic), so pick the wiring to match the pin's
  idle level. (For a button-to-GND, add an external pull-up and set
  `button_active_low = true`.)

## Transport

The agent serves a binary WebSocket on the configured setup address
(`network.setup_bind_addr`, default `0.0.0.0:9091`). The same server is
reachable two ways:

- **Over the Hosted Network** — join the `Bebop-XXXX` hotspot (WPA2), then
  connect to the gateway (`192.168.42.1:9091` by default).
- **Over the LAN** — once the robot is on Wi-Fi in Known Network mode, use
  its normal address (`bebop.local` resolves via mDNS/avahi on most
  networks).

Endpoints:

| Path | Purpose |
|---|---|
| `/healthz`  | Liveness probe; returns `ok`. Used by the app's pre-flight. |
| `/ws` | WebSocket upgrade; one `ClientRequest` per binary frame. |
| `/` | Status page (robot name, mode, Wi-Fi/Hosted state). |

## Framing

Each WebSocket binary frame carries exactly one `bebop.v1.ClientRequest`
(agent-bound) or `bebop.v1.AgentResponse` (app-bound), encoded with `prost`
on the agent side and `@bufbuild/protobuf` on the app side. There is no
extra length prefix — the WebSocket frame boundary is the message boundary.

## Messages

`bebop.proto` defines the provisioning surface:

- `GetDeviceInfo` / `DeviceInfo` — serial, model, agent version, JetPack,
  hostname.
- `ScanWifi` / `WifiScanResult` — nearby networks.
- `SetWifiCredentials` / `WifiStatus` — join a network.
- `GetWifiStatus` / `WifiStatus` — current link.
- `GetRobotConfig` / `SetRobotConfig` / `RobotConfig` — robot name.
- `GetNetworkConfig` / `SetNetworkConfig` / `NetworkConfig` — the Hosted
  Network settings (`ap_ssid`, `ap_password`, `ap_band`) plus the read-only
  `mode` and `ap_address`.

## Provisioning Wi-Fi

`SetWifiCredentials` behaves differently per mode:

- **Known Network (`client`)** — the robot joins immediately.
- **Hosted Network (`ap`)** — the profile is **saved but not applied**; the
  hotspot stays up so the current session isn't killed. The robot joins the
  saved network only when the button switches it to Known Network, at which
  point the profile autoconnects.

The app's Wi-Fi screen shows a "saved — press the button to switch" confirmation
when provisioning while Hosted.

## Editing the Hosted Network

The app's dashboard exposes the Hosted Network settings (SSID, password,
band 2.4/5 GHz) via `SetNetworkConfig`. `mode` is **read-only** in the API.
Changing the SSID/password/band while hosting recreates and re-raises the
hotspot, which briefly drops connected devices — reconnect with the new
credentials. An empty `ap_password` keeps the existing passphrase, and
responses never include it.

## Bench-verifying the button

The Jetson pinmux fixes each pin's idle level, and the runtime bias request
is effectively cosmetic — so confirm the wiring matches the idle level
before relying on the button.

```sh
# Idle level on header pin 32 (gpiochip0 line 41). With the default
# active-high wiring (switch to 3.3 V) this should read 0.
gpioget gpiochip0 105

# Watch edges while pressing the switch. Stop the agent first so it
# releases the line; expect a rising edge on press for active-high.
sudo systemctl stop bebop-agent
gpiomon gpiochip0 105          # Ctrl-C to exit; press the button
sudo systemctl start bebop-agent

# End-to-end: press the button, then watch the toggle + hotspot come up.
journalctl -u bebop-agent -f
# ... press the button ...
# expect: "button pressed" -> "mode button toggled network mode mode=ap"
#         -> "Hosted Network raised ssid=Bebop-XXXX"
```

To go back to Known Network, press the button again. If the hotspot is up,
join `Bebop-XXXX` on a phone/PC and open `http://192.168.42.1:9091`.

## Regenerating bindings

The Rust types are generated at build time by `bebop-proto/build.rs` from
`jetson-agent/bebop-proto/proto/bebop.proto`. The TypeScript bindings are
generated (and committed) with:

```sh
cd bebop-app && npm run gen-proto
```

Keep the `.proto` as the single source of truth for both sides.

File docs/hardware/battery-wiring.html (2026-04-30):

# ⚡ 13S2P 21700 Battery Pack — Option 2 (Mirrored)

## 4 Rows × 7 Columns — Vertical Pairs — Bottom Half Mirrored for Short S6→S7 Hop

🔼 Top View (Looking Down)

Positive (+) terminal up

Negative (−) terminal up

Empty slot

Nickel strip (top face)

Nickel strip (bottom face)

BMS balance wire tap

Thermistor probe

### 🔌 BMS & Charger Wiring Schematic

Layout — Option 2 (Mirrored Bottom Half)
Configuration: 13S2P = 26 cells, 2 empty slots (col 6, rows 0–1).
Top Half (Rows 0–1): S1→S2→…→S6, flowing left to right. Empty slots at column 6.
Bottom Half (Rows 2–3): S7→S8→…→S13, flowing right to left (mirrored). S7 at col 6, S13 at col 0.
Why Mirrored? S6 (col 5, top half) → S7 (col 6, bottom half) is now a 1-column hop across the gap — same distance as every other series connection. No long bus bar needed!
Polarity: Same pattern for both halves: even cols (+) up, odd cols (−) up. Series connections alternate between top face and bottom face strips.
Series Flow: S1(col0)→…→S6(col5) ↓ S7(col6)→S8(col5)→…→S13(col0). Forms a "U" shape.
Terminals: B−/PACK− (from S1, col 0 left) and PACK+ (from S13, col 0 left) — both on the left edge for clean wiring to BMS and load.
BMS Taps: 14 balance wires (B0–B13) at series junctions, extending to nearest edge.
⚠️ Wire Gauge for S6→S7: This carries full pack current (up to 40A). Use 8–10 AWG silicone wire or thick copper bus bar/strap. 22 AWG is dangerously undersized (~7A max). All series connections should be rated for full pack current.
Nickel Strips: Use 0.2mm × 30mm pure nickel or 0.15mm copper-nickel for parallel connections. For series connections (full current path), double-stack strips or use thicker stock.
Thermistor Placement (2 probes): T1 = center of top half (gap between S3/S4, rows 0–1). T2 = center of bottom half (gap between S10/S9, rows 2–3). These are the most thermally insulated spots — surrounded by cells on all 4 sides with the worst airflow. Press the NTC bead flat against the cell sidewall and secure with kapton tape. Route the thin sensor wires to the BMS NTC input.
Nominal: 46.8V | Charge: 54.6V | Cells: 21700

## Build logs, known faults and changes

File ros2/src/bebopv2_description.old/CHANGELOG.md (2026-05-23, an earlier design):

# Changelog

All notable changes to the `bebopv2_description` package are documented here.
The format is based on [Keep a Changelog](https://keepachangelog.com/en/1.1.0/).

## [Unreleased] – 2026-05-23

### Summary

Reworked the leg kinematic chain to fix incorrect joint nomenclature and ship
the redesigned hip flexion assembly from the latest CAD revision.

The previous tree mislabeled the joint immediately below `base_link` as
"hip abduction" when it was in fact the flexion (pitch) axis. The chain has
been renamed end-to-end so the joint names now match their actual anatomical
function. The first leg segment off `base_link` is also a new physical part,
not just a rename – it carries new mass, inertia, and mesh geometry.

### New kinematic chain

```
base_link
  └─ hip_flexion_{left,right}_joint   (revolute, pitch, Y axis)   [was: hip_abduction_*_joint]
       └─ hip_flexion_{left,right}_1                              [redesigned link; new mesh + inertia]
            └─ hip_abduction_{left,right}_joint  (revolute, roll, X axis)  [was: femur_*_joint]
                 └─ hip_abduction_{left,right}_1                 [was: femur_*_1; mesh + inertia unchanged]
                      └─ knee_flexion_{left,right}_joint  (revolute, pitch, Y axis)  [was: shin_*_joint]
                           └─ knee_flexion_{left,right}_1        [was: shin_*_1; mesh + inertia unchanged]
                                └─ foot_{left,right}_joint  (revolute, pitch, Y axis)
                                     └─ foot_{left,right}_1
```

### Changed – Links

| Old name | New name | Notes |
|---|---|---|
| `hip_abduction_{left,right}_1` | `hip_flexion_{left,right}_1` | **Renamed and redesigned.** New mesh, mass 1.000 kg → 1.1494 kg, new inertia tensor and CoM. |
| `femur_{left,right}_1` | `hip_abduction_{left,right}_1` | Renamed only. Mesh, mass (1.7420 kg) and inertia carried over. |
| `shin_{left,right}_1` | `knee_flexion_{left,right}_1`  | Renamed only. Mesh, mass (0.1137 kg) and inertia carried over. |
| `foot_{left,right}_1` | `foot_{left,right}_1` | Unchanged. |
| `base_link` | `base_link` | Mass refined from CAD: 7.0 kg → 6.70 kg; inertia tensor rescaled accordingly. Mesh unchanged. |

### Changed – Joints

| Old name | New name | Notes |
|---|---|---|
| `hip_abduction_{left,right}_joint`| `hip_flexion_{left,right}_joint`  | Renamed to reflect actual pitch-axis function. Parent/child updated to new links. Limits unchanged: ±0.785398 rad (±45°). |
| `femur_{left,right}_joint` | `hip_abduction_{left,right}_joint`| Renamed. Origin moved from `(0.02955, ±0.07, 0)` to `(0.02955, 0, -0.14)` to match the new hip_flexion link geometry. Limits tightened (see below). |
| `shin_{left,right}_joint` | `knee_flexion_{left,right}_joint` | Renamed; parent link updated to new `hip_abduction_*_1`. Origin and limits unchanged. |
| `foot_{left,right}_joint` | `foot_{left,right}_joint` | Unchanged. Parent link reference updated to `knee_flexion_*_1`. |

#### Joint limit changes (`hip_abduction_*_joint`, formerly `femur_*_joint`)

| Side  | Old upper / lower (rad) | New upper / lower (rad) |
|---|---|---|
| Right | +0.349066 / −0.785398 | +0.174533 / −0.349066 |
| Left  | +0.785398 / −0.349066 | +0.349066 / −0.174533 |

Travel range halved on both sides to reflect the mechanical hard stops of the
redesigned hip flexion bracket.

#### Hip flexion mount offsets (from `base_link`)

- Right: `(-0.003527, -0.1495, 0.013)` → `(-0.003527, -0.1503, 0.013)`
- Left:  `(-0.003789,  0.1505, 0.013132)` (unchanged)

### Added – Meshes

- `meshes/hip_flexion_left_1.stl` (≈2.76 MB) – new redesigned part.
- `meshes/hip_flexion_right_1.stl` (≈2.76 MB) – new redesigned part.
- `meshes/knee_flexion_left_1.stl` (≈282 KB) – renamed from `shin_left_1.stl`.
- `meshes/knee_flexion_right_1.stl` (≈282 KB) – renamed from `shin_right_1.stl`.

### Changed – Meshes

- `meshes/hip_abduction_left_1.stl` and `meshes/hip_abduction_right_1.stl`
  now contain the **former `femur_*_1.stl` geometry** (≈7.75 MB each). The
  filename is reused; the geometry it points at is the long thigh segment, not
  the old triangular hip bracket.

### Removed – Meshes

- `meshes/femur_left_1.stl`, `meshes/femur_right_1.stl` (content moved to
  `hip_abduction_*_1.stl`).
- `meshes/shin_left_1.stl`, `meshes/shin_right_1.stl` (content moved to
  `knee_flexion_*_1.stl`).
- The previous `hip_abduction_*_1.stl` (≈3.08 MB triangular hip bracket) is
  superseded by the redesigned `hip_flexion_*_1.stl` parts.

### Updated files

- `urdf/bebopv2.xacro` – all link names, joint names, parent/child references,
  origins, and inertials updated to match the new chain.
- `urdf/bebopv2.gazebo` – `<gazebo reference="…">` entries updated for the new
  link names (`hip_flexion_*_1`, `hip_abduction_*_1`, `knee_flexion_*_1`).

### Migration notes for downstream consumers

Anything that referred to the old joint or link names needs updating. The
direct rename map is:

```
hip_abduction_{left,right}_joint  →  hip_flexion_{left,right}_joint
femur_{left,right}_joint          →  hip_abduction_{left,right}_joint
shin_{left,right}_joint           →  knee_flexion_{left,right}_joint
foot_{left,right}_joint           →  foot_{left,right}_joint               (unchanged)

hip_abduction_{left,right}_1      →  hip_flexion_{left,right}_1            (also redesigned)
femur_{left,right}_1              →  hip_abduction_{left,right}_1
shin_{left,right}_1               →  knee_flexion_{left,right}_1
foot_{left,right}_1               →  foot_{left,right}_1                    (unchanged)
```

Known dependents that likely need to be updated in lock-step:

- `ros2/src/bebopv2_description/config/` – any controller / joint-list YAMLs.
- `ros2/src/bebopv2_description/urdf/bebopv2.ros2control` – joint references.
- `ros2/src/bebopv2_description/launch/` – any joint name remappings.
- `firmware/bebop-linux/config/bebop_v2.yaml` – joint ordering / names.
- `sim/usd/bebopv2/` – USD physics payload (also referenced in the old base_link inertia comment).
- `bebop-app` Motor Bench / telemetry views that hard-code joint labels.

### Rationale

The previous naming was inherited from an earlier CAD revision in which the
top hip link was modeled as a simple abduction bracket. In the current
mechanical design the joint immediately under the torso is the pitch (flexion)
axis, and the abduction (roll) axis lives one link down inside the hip
assembly. Aligning the URDF names with the actual anatomy avoids a
long-running source of confusion in controls code, telemetry, and any
human-facing labels.

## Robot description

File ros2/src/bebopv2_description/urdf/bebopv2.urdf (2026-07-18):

<?xml version="1.0" ?>
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
<robot name="bebopv2">
  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
  <link name="base_link">
    <inertial>
      <origin rpy="0 0 0" xyz="-8.495725208879161e-05 0.0020602048068726576 0.06042048201634313"/>
      <mass value="6.6999999999999975"/>
      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
    </inertial>
    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
  </link>
  <link name="knee_flexion_left_1">
    <inertial>
      <origin rpy="0 0 0" xyz="3.846626425058064e-05 0.01659814266918333 -0.12318431182483869"/>
      <mass value="0.11370113593752607"/>
      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
    </inertial>
    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
  </link>
  <link name="knee_flexion_right_1">
    <inertial>
      <origin rpy="0 0 0" xyz="-0.0021891088643420653 -0.01659808446088712 -0.12316566275884544"/>
      <mass value="0.11369998148988655"/>
      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
    </inertial>
    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
  </link>
  <link name="hip_flexion_right_1">
    <inertial>
      <origin rpy="0 0 0" xyz="0.0013636431736272592 -0.005138644819907778 -0.11306629060566109"/>
      <mass value="1.1494365230098111"/>
      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
    </inertial>
    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
  </link>
  <link name="hip_flexion_left_1">
    <inertial>
      <origin rpy="0 0 0" xyz="0.0013616527842525501 0.005166034468434444 -0.11306634650440041"/>
      <mass value="1.1494341700004236"/>
      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
    </inertial>
    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
  </link>
  <link name="hip_abduction_right_1">
    <inertial>
      <origin rpy="0 0 0" xyz="0.03210238385368529 -0.00031798171381045015 -0.1813015006925155"/>
      <mass value="1.741992832749943"/>
      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
    </inertial>
    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
  </link>
  <link name="hip_abduction_left_1">
    <inertial>
      <origin rpy="0 0 0" xyz="0.03177093685294447 0.00031798236885224873 -0.18130159101260016"/>
      <mass value="1.741996667034525"/>
      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
    </inertial>
    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
  </link>
  <link name="foot_right_1">
    <inertial>
      <origin rpy="0 0 0" xyz="0.011485686877247665 0.022215465357853237 -0.023509071789787894"/>
      <mass value="0.8000056692711454"/>
      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
    </inertial>
    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
  </link>
  <link name="foot_left_1">
    <inertial>
      <origin rpy="0 0 0" xyz="0.011473956574195115 -0.025038911721186607 -0.023484348928246468"/>
      <mass value="0.7999816122276703"/>
      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
    </inertial>
    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
  </link>
  <joint name="knee_flexion_left_joint" type="revolute">
    <origin rpy="0 0 0" xyz="0.0375 0.0277 -0.294034"/>
    <parent link="hip_abduction_left_1"/>
    <child link="knee_flexion_left_1"/>
    <axis xyz="0.0 1.0 0.0"/>
    <limit effort="100" lower="-0.785398" upper="1.570796" velocity="100"/>
  </joint>
  <joint name="knee_flexion_right_joint" type="revolute">
    <origin rpy="0 0 0" xyz="0.0375 -0.0277 -0.294034"/>
    <parent link="hip_abduction_right_1"/>
    <child link="knee_flexion_right_1"/>
    <axis xyz="-0.0 -1.0 -0.0"/>
    <limit effort="100" lower="-1.570796" upper="0.785398" velocity="100"/>
  </joint>
  <joint name="hip_flexion_right_joint" type="revolute">
    <origin rpy="0 0 0" xyz="-0.003527 -0.1503 0.013"/>
    <parent link="base_link"/>
    <child link="hip_flexion_right_1"/>
    <axis xyz="-0.0 -1.0 -0.0"/>
    <limit effort="100" lower="-0.785398" upper="0.785398" velocity="100"/>
  </joint>
  <joint name="hip_flexion_left_joint" type="revolute">
    <origin rpy="0 0 0" xyz="-0.003789 0.1505 0.013132"/>
    <parent link="base_link"/>
    <child link="hip_flexion_left_1"/>
    <axis xyz="0.0 1.0 -0.0"/>
    <limit effort="100" lower="-0.785398" upper="0.785398" velocity="100"/>
  </joint>
  <joint name="hip_abduction_right_joint" type="revolute">
    <origin rpy="0 0 0" xyz="0.02955 0.0 -0.14"/>
    <parent link="hip_flexion_right_1"/>
    <child link="hip_abduction_right_1"/>
    <axis xyz="1.0 0.0 0.0"/>
    <limit effort="100" lower="-0.349066" upper="0.174533" velocity="100"/>
  </joint>
  <joint name="hip_abduction_left_joint" type="revolute">
    <origin rpy="0 0 0" xyz="0.02955 0.0 -0.14"/>
    <parent link="hip_flexion_left_1"/>
    <child link="hip_abduction_left_1"/>
    <axis xyz="1.0 -0.0 0.0"/>
    <limit effort="100" lower="-0.174533" upper="0.349066" velocity="100"/>
  </joint>
  <joint name="foot_right_joint" type="revolute">
    <origin rpy="0 0 0" xyz="-0.004429 0.0 -0.253461"/>
    <parent link="knee_flexion_right_1"/>
    <child link="foot_right_1"/>
    <axis xyz="-0.0 -1.0 -0.0"/>
    <limit effort="100" lower="-0.523599" upper="0.523599" velocity="100"/>
  </joint>
  <joint name="foot_left_joint" type="revolute">
    <origin rpy="0 0 0" xyz="4e-06 0.0 -0.2535"/>
    <parent link="knee_flexion_left_1"/>
    <child link="foot_left_1"/>
    <axis xyz="-0.0 1.0 0.0"/>
    <limit effort="100" lower="-0.523599" upper="0.523599" velocity="100"/>
  </joint>
</robot>

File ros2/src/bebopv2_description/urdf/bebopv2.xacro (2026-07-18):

<?xml version="1.0" ?>
<robot name="bebopv2" xmlns:xacro="http://www.ros.org/wiki/xacro">

<xacro:include filename="$(find bebopv2_description)/urdf/materials.xacro" />
<xacro:include filename="$(find bebopv2_description)/urdf/bebopv2.ros2control" />
<xacro:include filename="$(find bebopv2_description)/urdf/bebopv2.gazebo" />
<link name="base_link">
  <inertial>
    <origin xyz="-8.495725208879161e-05 0.0020602048068726576 0.06042048201634313" rpy="0 0 0"/>
    <mass value="6.6999999999999975"/>
    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
  </inertial>
  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
</link>

<link name="knee_flexion_left_1">
  <inertial>
    <origin xyz="3.846626425058064e-05 0.01659814266918333 -0.12318431182483869" rpy="0 0 0"/>
    <mass value="0.11370113593752607"/>
    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
  </inertial>
  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
</link>

<link name="knee_flexion_right_1">
  <inertial>
    <origin xyz="-0.0021891088643420653 -0.01659808446088712 -0.12316566275884544" rpy="0 0 0"/>
    <mass value="0.11369998148988655"/>
    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
  </inertial>
  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
</link>

<link name="hip_flexion_right_1">
  <inertial>
    <origin xyz="0.0013636431736272592 -0.005138644819907778 -0.11306629060566109" rpy="0 0 0"/>
    <mass value="1.1494365230098111"/>
    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
  </inertial>
  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
</link>

<link name="hip_flexion_left_1">
  <inertial>
    <origin xyz="0.0013616527842525501 0.005166034468434444 -0.11306634650440041" rpy="0 0 0"/>
    <mass value="1.1494341700004236"/>
    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
  </inertial>
  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
</link>

<link name="hip_abduction_right_1">
  <inertial>
    <origin xyz="0.03210238385368529 -0.00031798171381045015 -0.1813015006925155" rpy="0 0 0"/>
    <mass value="1.741992832749943"/>
    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
  </inertial>
  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
</link>

<link name="hip_abduction_left_1">
  <inertial>
    <origin xyz="0.03177093685294447 0.00031798236885224873 -0.18130159101260016" rpy="0 0 0"/>
    <mass value="1.741996667034525"/>
    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
  </inertial>
  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
</link>

<link name="foot_right_1">
  <inertial>
    <origin xyz="0.011485686877247665 0.022215465357853237 -0.023509071789787894" rpy="0 0 0"/>
    <mass value="0.8000056692711454"/>
    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
  </inertial>
  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
</link>

<link name="foot_left_1">
  <inertial>
    <origin xyz="0.011473956574195115 -0.025038911721186607 -0.023484348928246468" rpy="0 0 0"/>
    <mass value="0.7999816122276703"/>
    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
  </inertial>
  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
</link>

<joint name="knee_flexion_left_joint" type="revolute">
  <origin xyz="0.0375 0.0277 -0.294034" rpy="0 0 0"/>
  <parent link="hip_abduction_left_1"/>
  <child link="knee_flexion_left_1"/>
  <axis xyz="0.0 1.0 0.0"/>
  <limit upper="1.570796" lower="-0.785398" effort="100" velocity="100"/>
</joint>

<joint name="knee_flexion_right_joint" type="revolute">
  <origin xyz="0.0375 -0.0277 -0.294034" rpy="0 0 0"/>
  <parent link="hip_abduction_right_1"/>
  <child link="knee_flexion_right_1"/>
  <axis xyz="-0.0 -1.0 -0.0"/>
  <limit upper="0.785398" lower="-1.570796" effort="100" velocity="100"/>
</joint>

<joint name="hip_flexion_right_joint" type="revolute">
  <origin xyz="-0.003527 -0.1503 0.013" rpy="0 0 0"/>
  <parent link="base_link"/>
  <child link="hip_flexion_right_1"/>
  <axis xyz="-0.0 -1.0 -0.0"/>
  <limit upper="0.785398" lower="-0.785398" effort="100" velocity="100"/>
</joint>

<joint name="hip_flexion_left_joint" type="revolute">
  <origin xyz="-0.003789 0.1505 0.013132" rpy="0 0 0"/>
  <parent link="base_link"/>
  <child link="hip_flexion_left_1"/>
  <axis xyz="0.0 1.0 -0.0"/>
  <limit upper="0.785398" lower="-0.785398" effort="100" velocity="100"/>
</joint>

<joint name="hip_abduction_right_joint" type="revolute">
  <origin xyz="0.02955 0.0 -0.14" rpy="0 0 0"/>
  <parent link="hip_flexion_right_1"/>
  <child link="hip_abduction_right_1"/>
  <axis xyz="1.0 0.0 0.0"/>
  <limit upper="0.174533" lower="-0.349066" effort="100" velocity="100"/>
</joint>

<joint name="hip_abduction_left_joint" type="revolute">
  <origin xyz="0.02955 0.0 -0.14" rpy="0 0 0"/>
  <parent link="hip_flexion_left_1"/>
  <child link="hip_abduction_left_1"/>
  <axis xyz="1.0 -0.0 0.0"/>
  <limit upper="0.349066" lower="-0.174533" effort="100" velocity="100"/>
</joint>

<joint name="foot_right_joint" type="revolute">
  <origin xyz="-0.004429 0.0 -0.253461" rpy="0 0 0"/>
  <parent link="knee_flexion_right_1"/>
  <child link="foot_right_1"/>
  <axis xyz="-0.0 -1.0 -0.0"/>
  <limit upper="0.523599" lower="-0.523599" effort="100" velocity="100"/>
</joint>

<joint name="foot_left_joint" type="revolute">
  <origin xyz="4e-06 0.0 -0.2535" rpy="0 0 0"/>
  <parent link="knee_flexion_left_1"/>
  <child link="foot_left_1"/>
  <axis xyz="-0.0 1.0 0.0"/>
  <limit upper="0.523599" lower="-0.523599" effort="100" velocity="100"/>
</joint>

</robot>

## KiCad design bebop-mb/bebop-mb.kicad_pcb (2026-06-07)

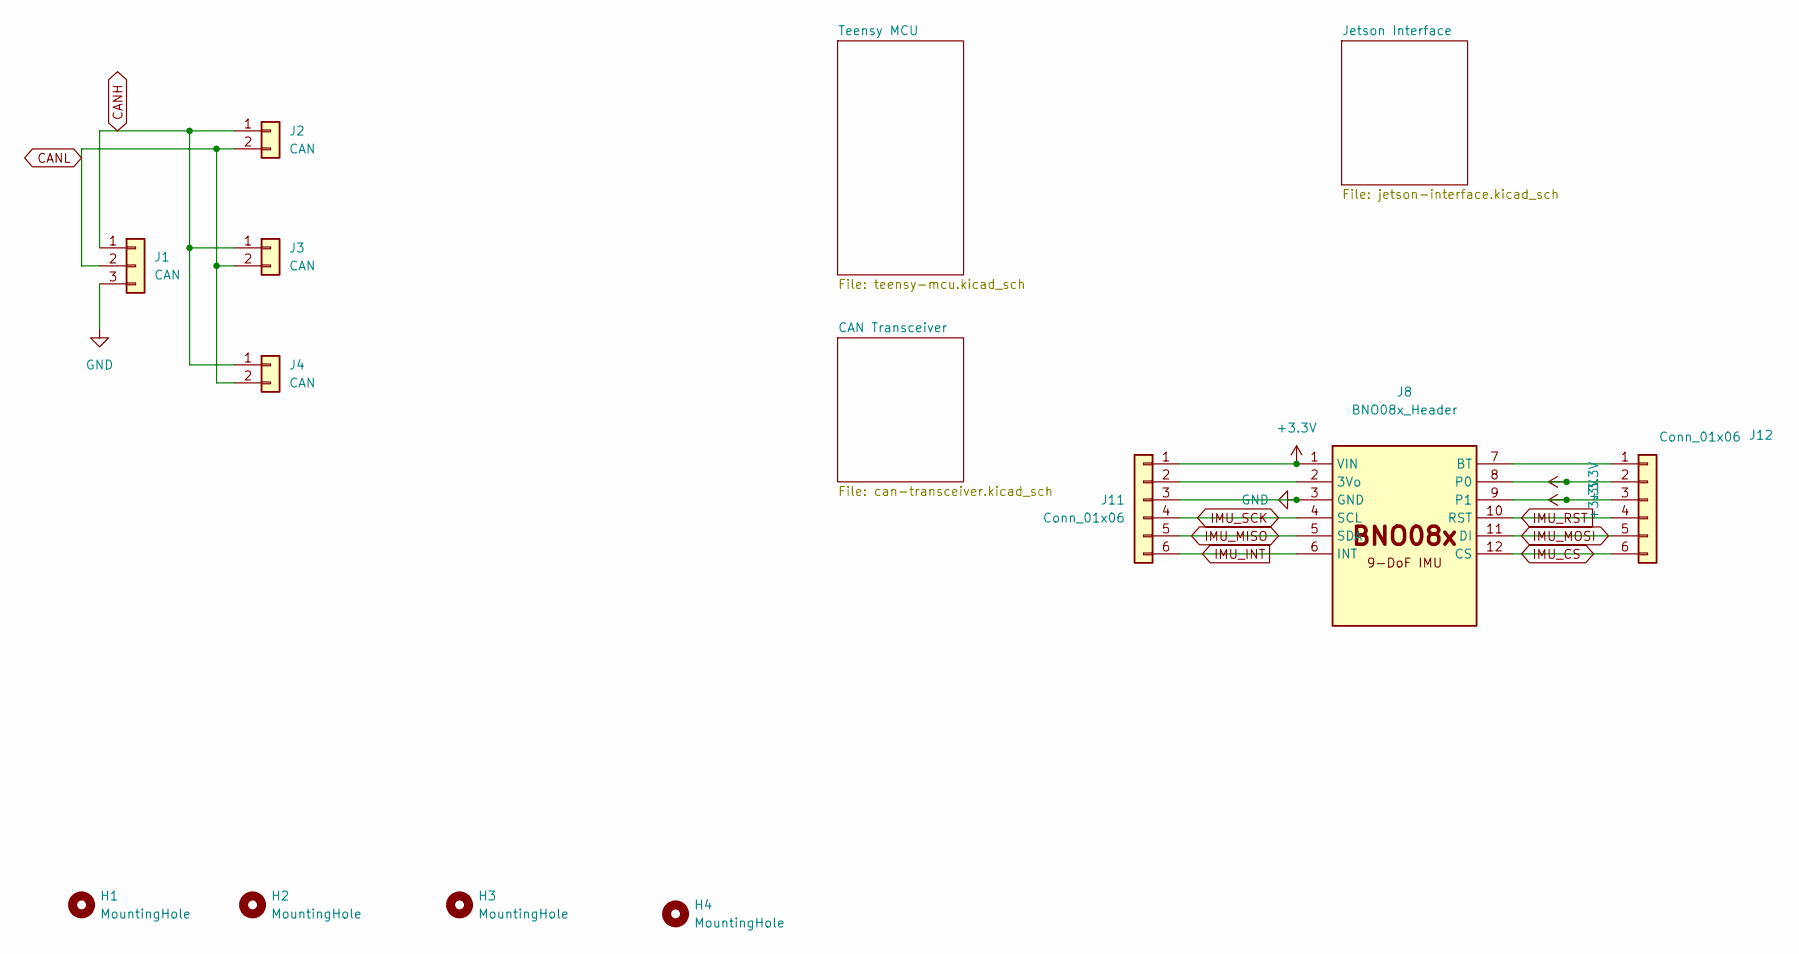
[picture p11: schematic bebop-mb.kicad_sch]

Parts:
H1, H2, H3, H4: MountingHole; MountingHole_3.2mm_M3_ISO14580
J1: CAN; TerminalBlock_Xinya_XY308-2.54-3P_1x03_P2.54mm_Horizontal; Manufacturer Part Number XY308-3P
J2, J3, J4: CAN; JST_GH_SM02B-GHS-TB_1x02-1MP_P1.25mm_Horizontal; Manufacturer Part Number SM02B-GHS-TB(LF)(SN)
J8: BNO08x_Header; BNO08x_Breakout; Manufacturer Part Number PPTC061LFBN-RC
J11, J12: Conn_01x06; PinSocket_1x06_P2.54mm_Vertical; Manufacturer Part Number PPTC061LFBN-RC

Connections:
+3.3V: J8.1 (VIN), J8.8 (P0), J8.9 (P1), J11.1, J12.2, J12.3; also elsewhere on the board
CANH: J1.1, J2.1, J3.1, J4.1; also elsewhere on the board
CANL: J1.2, J2.2, J3.2, J4.2; also elsewhere on the board
GND: J1.3, J8.3 (GND), J11.3; also elsewhere on the board
IMU_CS: J8.12 (CS), J12.6; also elsewhere on the board
IMU_INT: J8.6 (INT), J11.6; also elsewhere on the board
IMU_MISO: J8.5 (SDA), J11.5; also elsewhere on the board
IMU_MOSI: J8.11 (DI), J12.5; also elsewhere on the board
IMU_RST: J8.10 (RST), J12.4; also elsewhere on the board
IMU_SCK: J8.4 (SCL), J11.4; also elsewhere on the board
unnamed: J8.2 (3Vo), J11.2
unnamed: J8.7 (BT), J12.1

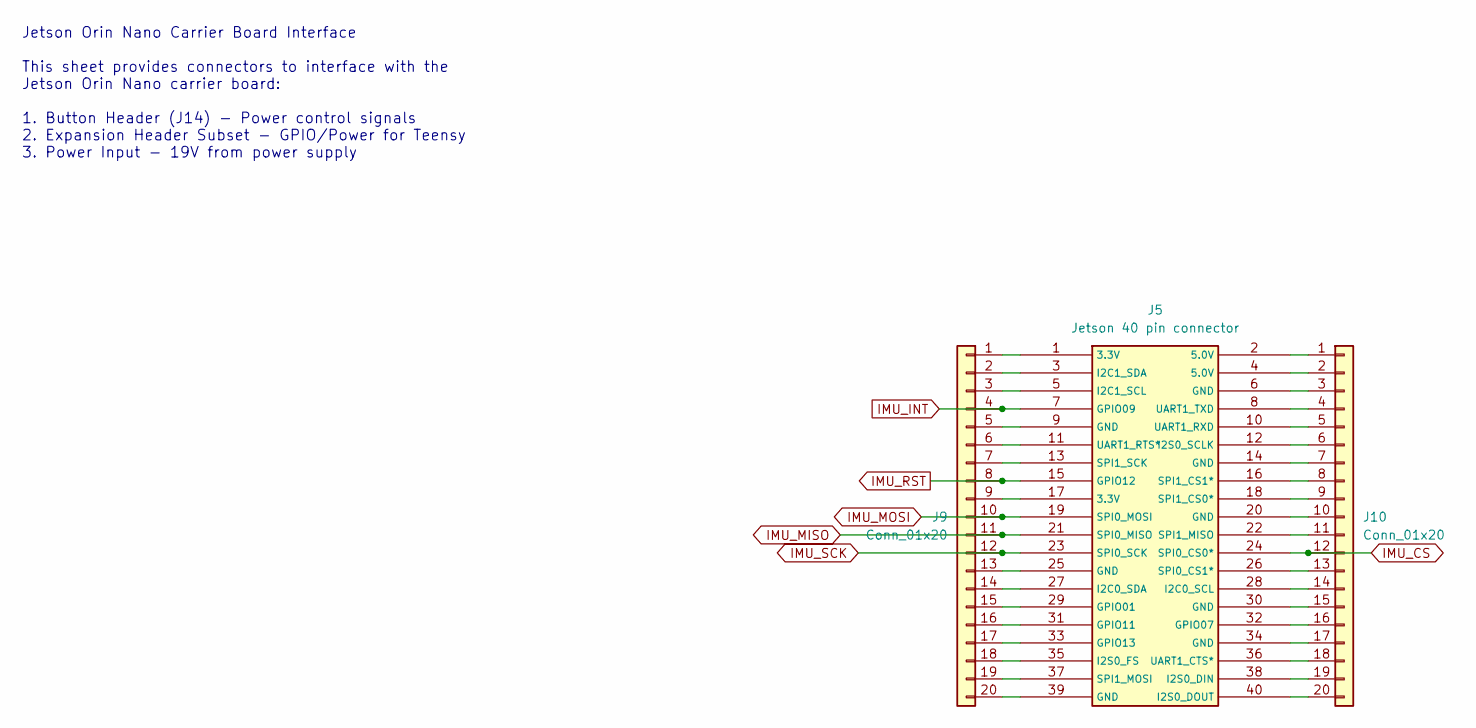
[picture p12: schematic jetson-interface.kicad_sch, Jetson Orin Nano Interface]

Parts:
J5: Jetson 40 pin connector; IDC-Header_2x20_P2.54mm_Vertical; Manufacturer Part Number PPTC202LFBN-RC
J9, J10: Conn_01x20; PinSocket_1x20_P2.54mm_Vertical; Manufacturer Part Number PPTC201LFBN-RC

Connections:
IMU_CS: J5.24 (SPI0_CS0*), J10.12; also elsewhere on the board
IMU_INT: J5.7 (GPIO09), J9.4; also elsewhere on the board
IMU_MISO: J5.21 (SPI0_MISO), J9.11; also elsewhere on the board
IMU_MOSI: J5.19 (SPI0_MOSI), J9.10; also elsewhere on the board
IMU_RST: J5.15 (GPIO12), J9.8; also elsewhere on the board
IMU_SCK: J5.23 (SPI0_SCK), J9.12; also elsewhere on the board
unnamed: J5.29 (GPIO01), J9.15
unnamed: J5.31 (GPIO11), J9.16
unnamed: J5.33 (GPIO13), J9.17
unnamed: J5.27 (I2C0_SDA), J9.14
unnamed: J5.5 (I2C1_SCL), J9.3
unnamed: J5.3 (I2C1_SDA), J9.2
unnamed: J5.35 (I2S0_FS), J9.18
unnamed: J5.37 (SPI1_MOSI), J9.19
unnamed: J5.13 (SPI1_SCK), J9.7
unnamed: J5.11 (UART1_RTS*), J9.6
unnamed: J5.1 (3.3V), J9.1
unnamed: J5.9 (GND), J9.5
unnamed: J5.17 (3.3V), J9.9
unnamed: J5.25 (GND), J9.13
unnamed: J5.39 (GND), J9.20
unnamed: J5.2 (5.0V), J10.1
unnamed: J5.4 (5.0V), J10.2
unnamed: J5.6 (GND), J10.3
unnamed: J5.8 (UART1_TXD), J10.4
unnamed: J5.10 (UART1_RXD), J10.5
unnamed: J5.12 (I2S0_SCLK), J10.6
unnamed: J5.14 (GND), J10.7
unnamed: J5.16 (SPI1_CS1*), J10.8
unnamed: J5.18 (SPI1_CS0*), J10.9
unnamed: J5.20 (GND), J10.10
unnamed: J5.22 (SPI1_MISO), J10.11
unnamed: J5.26 (SPI0_CS1*), J10.13
unnamed: J5.28 (I2C0_SCL), J10.14
unnamed: J5.30 (GND), J10.15
unnamed: J5.32 (GPIO07), J10.16
unnamed: J5.34 (GND), J10.17
unnamed: J5.36 (UART1_CTS*), J10.18
unnamed: J5.38 (I2S0_DIN), J10.19
unnamed: J5.40 (I2S0_DOUT), J10.20

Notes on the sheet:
Jetson Orin Nano Carrier Board Interface This sheet provides connectors to interface with the Jetson Orin Nano carrier board: 1. Button Header (J14) - Power control signals 2. Expansion Header Subset - GPIO/Power for Teensy 3. Power Input - 19V from power supply

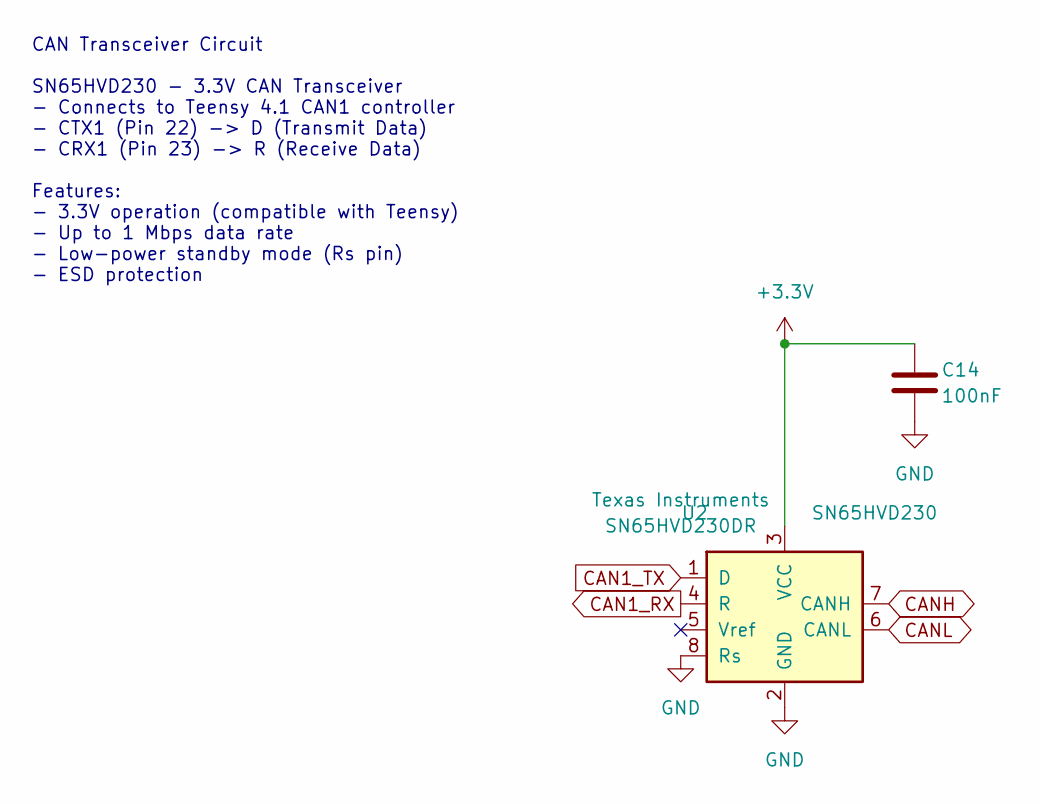
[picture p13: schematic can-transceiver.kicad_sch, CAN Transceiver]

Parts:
C14: 100nF; C_0603_1608Metric; Manufacturer Part Number GRM188R71H104KA93D
U2: SN65HVD230; SOIC-8_3.9x4.9mm_P1.27mm; Manufacturer Part Number SN65HVD230DR

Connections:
+3.3V: C14.1, U2.3 (VCC); also elsewhere on the board
CAN1_RX: U2.4 (R); also elsewhere on the board
CAN1_TX: U2.1 (D); also elsewhere on the board
CANH: U2.7 (CANH); also elsewhere on the board
CANL: U2.6 (CANL); also elsewhere on the board
GND: C14.2, U2.2 (GND), U2.8 (Rs); also elsewhere on the board

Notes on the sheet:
CAN Transceiver Circuit SN65HVD230 - 3.3V CAN Transceiver - Connects to Teensy 4.1 CAN1 controller - CTX1 (Pin 22) -> D (Transmit Data) - CRX1 (Pin 23) -> R (Receive Data) Features: - 3.3V operation (compatible with Teensy) - Up to 1 Mbps data rate - Low-power standby mode (Rs pin) - ESD protection

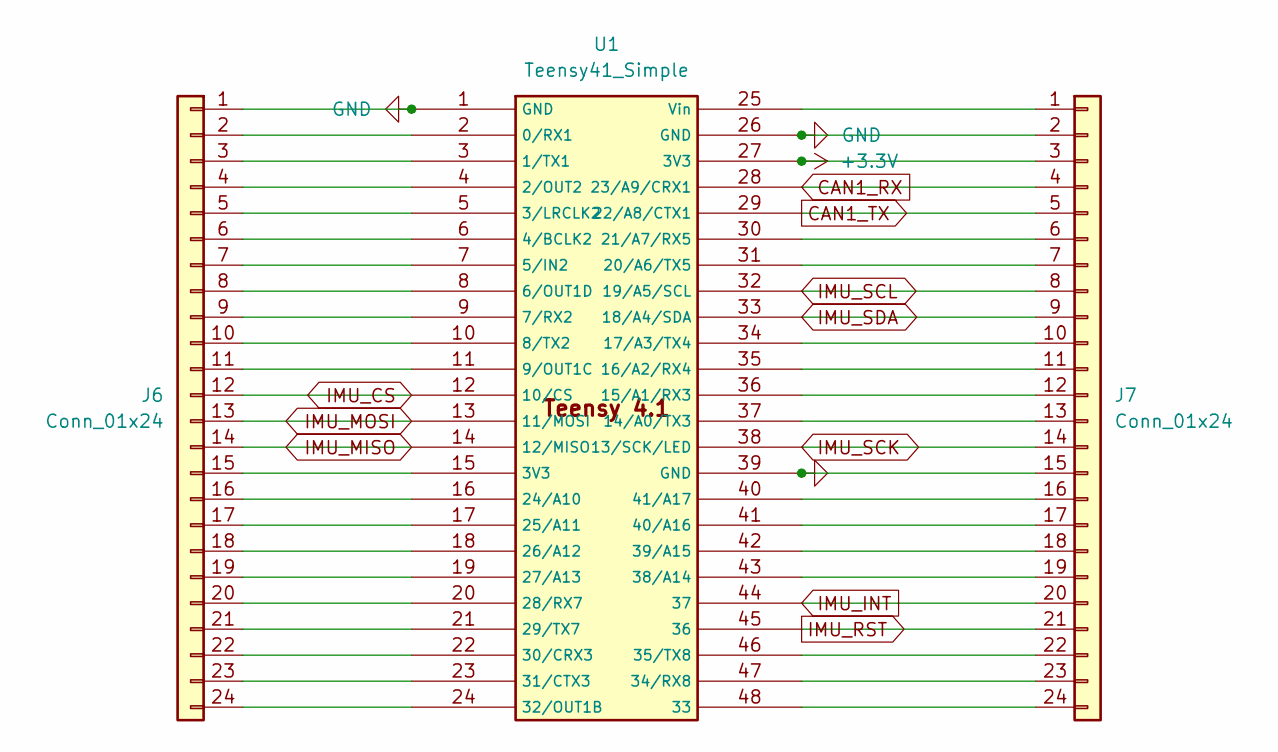
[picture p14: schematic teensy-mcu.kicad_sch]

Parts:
J6, J7: Conn_01x24; PinSocket_1x24_P2.54mm_Vertical; Manufacturer Part Number PPTC241LFBN-RC
U1: Teensy41_Simple; Manufacturer Part Number PPTC241LFBN-RC

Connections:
+3.3V: J7.3, U1.27 (3V3); also elsewhere on the board
CAN1_RX: J7.4, U1.28 (23/A9/CRX1); also elsewhere on the board
CAN1_TX: J7.5, U1.29 (22/A8/CTX1); also elsewhere on the board
GND: J6.1, J7.2, J7.15, U1.1 (GND), U1.26 (GND), U1.39 (GND); also elsewhere on the board
IMU_CS: J6.12, U1.12 (10/CS); also elsewhere on the board
IMU_INT: J7.20, U1.44 (37); also elsewhere on the board
IMU_MISO: J6.14, U1.14 (12/MISO); also elsewhere on the board
IMU_MOSI: J6.13, U1.13 (11/MOSI); also elsewhere on the board
IMU_RST: J7.21, U1.45 (36); also elsewhere on the board
IMU_SCK: J7.14, U1.38 (13/SCK/LED); also elsewhere on the board
IMU_SCL: J7.8, U1.32 (19/A5/SCL)
IMU_SDA: J7.9, U1.33 (18/A4/SDA)
unnamed: J6.2, U1.2 (0/RX1)
unnamed: J6.3, U1.3 (1/TX1)
unnamed: J6.4, U1.4 (2/OUT2)
unnamed: J6.5, U1.5 (3/LRCLK2)
unnamed: J6.6, U1.6 (4/BCLK2)
unnamed: J6.7, U1.7 (5/IN2)
unnamed: J6.8, U1.8 (6/OUT1D)
unnamed: J6.9, U1.9 (7/RX2)
unnamed: J6.10, U1.10 (8/TX2)
unnamed: J6.11, U1.11 (9/OUT1C)
unnamed: J6.15, U1.15 (3V3)
unnamed: J6.16, U1.16 (24/A10)
unnamed: J6.17, U1.17 (25/A11)
unnamed: J6.18, U1.18 (26/A12)
unnamed: J6.19, U1.19 (27/A13)
unnamed: J6.20, U1.20 (28/RX7)
unnamed: J6.21, U1.21 (29/TX7)
unnamed: J6.22, U1.22 (30/CRX3)
unnamed: J6.23, U1.23 (31/CTX3)
unnamed: J6.24, U1.24 (32/OUT1B)
unnamed: J7.1, U1.25 (Vin)
unnamed: J7.6, U1.30 (21/A7/RX5)
unnamed: J7.7, U1.31 (20/A6/TX5)
unnamed: J7.10, U1.34 (17/A3/TX4)
unnamed: J7.11, U1.35 (16/A2/RX4)
unnamed: J7.12, U1.36 (15/A1/RX3)
unnamed: J7.13, U1.37 (14/A0/TX3)
unnamed: J7.16, U1.40 (41/A17)
unnamed: J7.17, U1.41 (40/A16)
unnamed: J7.18, U1.42 (39/A15)
unnamed: J7.19, U1.43 (38/A14)
unnamed: J7.22, U1.46 (35/TX8)
unnamed: J7.23, U1.47 (34/RX8)
unnamed: J7.24, U1.48 (33)

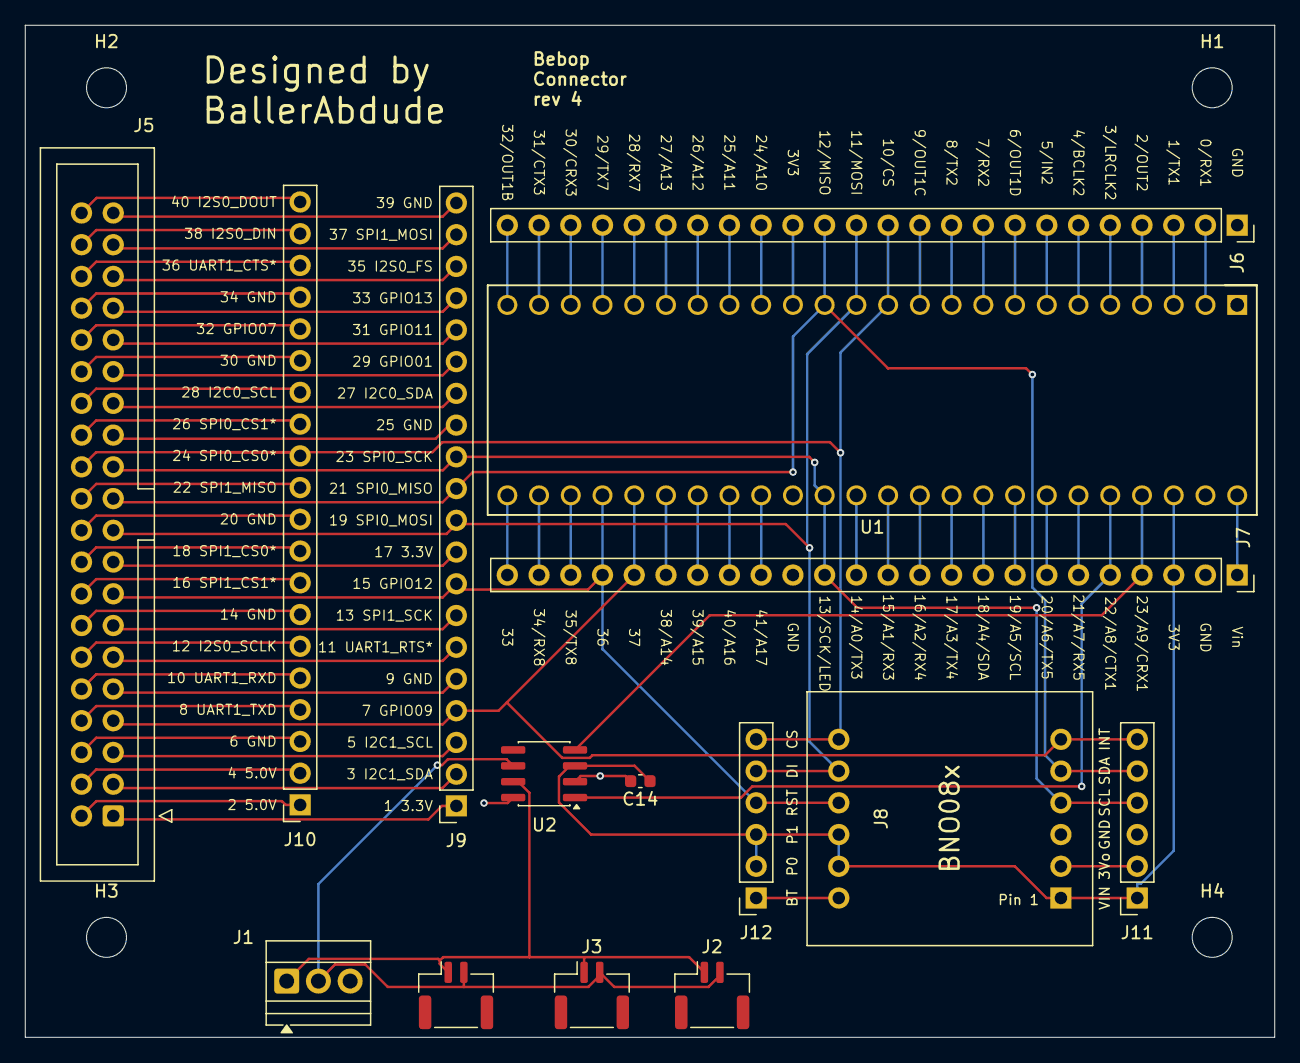
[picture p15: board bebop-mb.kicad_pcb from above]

Board: 2 copper layers, 100.0 x 81.0 mm, 19 parts (0 on the bottom side), 84 nets.

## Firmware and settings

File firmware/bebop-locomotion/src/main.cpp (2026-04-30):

/**
 * @file main.cpp
 * @brief Teensy 4.1 CAN Bridge for ROS 2 (micro-ROS)
 * 
 * This firmware acts as a bridge between ROS 2 and motor hardware.
 * It receives JointState commands via micro-ROS and translates them
 * to CAN messages for Robstride and ODrive motors.
 * 
 * Published Topics:
 *   /joint_states     - Position, velocity, torque feedback (100Hz)
 *   /imu/data         - IMU orientation and angular velocity (100Hz)
 *   /motor_temps      - Motor temperatures (10Hz)
 *   /motor_status     - Fault codes, enable states, voltages (10Hz)
 * 
 * Subscribed Topics:
 *   /joint_commands   - Position, velocity, torque commands
 */

#include <Arduino.h>
#include <FlexCAN_T4.h>
#include "BebopPolicy.h"  // Include generated policy

// Robot configuration and hardware
#include "RobotConfig.h"
#include "BNO085_IMU.h"

// Modular components
#include "SerialCommands.h"
#include "RosPublishers.h"

// ============================================================================
// CONFIGURATION
// ============================================================================

// POLICY CONFIGURATION (Must match training!)
#define HISTORY_STEPS 1
#define OBS_FRAME_DIM bebop_policy::OBS_DIM
#define TOTAL_OBS_DIM (OBS_FRAME_DIM * HISTORY_STEPS)

// TIMING
#define POLICY_RATE_HZ 100
#define POLICY_INTERVAL_US (1000000 / POLICY_RATE_HZ)
#define DECIMATION 1  // Run policy every N loops if loop is faster (e.g. 100Hz loop -> decimation 2)

// SAFETY LIMITS (policy output clamps - well within ODrive hardware limits of 40 rev/s)
const float MAX_LEG_POS_RAD = 0.8f;
const float MAX_WHEEL_VEL_RAD_S = 20.0f;  // ~3.2 rev/s - conservative for RL policy

// SCALES
const float SCALE_LIN_VEL = bebop_policy::SCALE_LIN_VEL;
const float SCALE_ANG_VEL = bebop_policy::SCALE_ANG_VEL;
const float SCALE_DOF_POS = bebop_policy::SCALE_DOF_POS;
const float SCALE_DOF_VEL = bebop_policy::SCALE_DOF_VEL;
const float SCALE_ACTION_LEGS = bebop_policy::SCALE_ACTION_LEGS;
const float SCALE_ACTION_WHEELS = bebop_policy::SCALE_ACTION_WHEELS;

const float CLIP_LIN_VEL = bebop_policy::CLIP_LIN_VEL;
const float CLIP_ANG_VEL = bebop_policy::CLIP_ANG_VEL;
const float CLIP_DOF_VEL = bebop_policy::CLIP_DOF_VEL;

// ============================================================================
// GLOBAL VARIABLES
// ============================================================================

// CAN bus instance (type defined in RobotConfig.h)
CANBusType canBus;

// Motor array
GenericMotor* joints[NUM_JOINTS];

// IMU
BNO085_IMU imu;

// Timing
uint32_t last_publish_time = 0;
uint32_t last_imu_publish_time = 0;
uint32_t last_imu_update_time = 0;
uint32_t last_diag_publish_time = 0;
uint32_t last_timing_report_ms = 0;

// Timing intervals
const uint32_t publish_interval_ms = 1000 / FEEDBACK_PUBLISH_HZ;  // 10ms for 100Hz
const uint32_t imu_publish_interval_ms = 10;   // 100 Hz IMU
const uint32_t imu_update_interval_ms = 5;     // 200 Hz IMU update
const uint32_t diag_publish_interval_ms = 100; // 10 Hz diagnostics

// Status LED
#define LED_PIN 13
bool led_state = false;

// CAN debug counters
volatile uint32_t can_rx_count = 0;
volatile uint32_t can_rx_std_count = 0;
volatile uint32_t can_rx_ext_count = 0;

// Debug flags (toggle via serial commands)
bool can_tx_debug = false;
bool can_rx_debug = false;
bool imu_debug = false;
bool status_logging = true;  // Periodic status output (every 2s)

// POLICY STATE
bebop_policy::Policy policy;
float current_obs[OBS_FRAME_DIM];
float history_buffer[TOTAL_OBS_DIM];
float action_buffer[bebop_policy::ACTION_DIM];
float last_action[bebop_policy::ACTION_DIM] = {0};

uint32_t last_policy_us = 0;
uint32_t step_count = 0;

// State Estimation
float est_base_lin_vel[3] = {0}; // [x, y, z] body frame
float est_projected_gravity[3] = {0, 0, -1};
float default_joint_pos[6] = {0.0f, 0.0f, 0.0f, 0.0f, 0.0f, 0.0f}; // Should match training

// Velocity estimation params
const float EST_WHEEL_RADIUS = 0.05f;
const float EST_VEL_FUSION = 0.05f;
const float EST_VEL_DECAY = 0.90f;
uint32_t last_vel_est_us = 0;

// ============================================================================
// HELPER FUNCTIONS
// ============================================================================

inline float clamp(float val, float min_val, float max_val) {
    return fmaxf(min_val, fminf(max_val, val));
}

void updateHistory(float* new_frame) {
    // Shift and insert logic (Simplified for HISTORY_STEPS=1 which is common)
    if (HISTORY_STEPS > 1) {
        memmove(&history_buffer[OBS_FRAME_DIM], &history_buffer[0], (HISTORY_STEPS - 1) * OBS_FRAME_DIM * sizeof(float));
    }
    memcpy(&history_buffer[0], new_frame, OBS_FRAME_DIM * sizeof(float));
}

void computeProjectedGravity() {
    // Compute R^T * [0, 0, -1] to get gravity in body frame
    // Must match IsaacLab's mdp.projected_gravity = quat_rotate_inverse(root_quat_w, [0,0,-1])
    float w = imu.quat_w;
    float x = imu.quat_x;
    float y = imu.quat_y;
    float z = imu.quat_z;
    
    est_projected_gravity[0] = 2.0f * (w * y - x * z);
    est_projected_gravity[1] = -2.0f * (w * x + y * z);
    est_projected_gravity[2] = -(w * w - x * x - y * y + z * z);
}

void updateVelocityEstimate(float dt) {
    if (dt <= 0.0f || dt > 0.1f) return;

    // 1. Wheel Odometry
    // Joints 4 and 5 are wheels (left, right)
    float avg_wheel_vel = (joints[4]->current_velocity + joints[5]->current_velocity) / 2.0f;
    float odom_vel_x = avg_wheel_vel * EST_WHEEL_RADIUS;
    
    // 2. Static Switch
    if (fabsf(avg_wheel_vel) < 0.1f) {
        est_base_lin_vel[0] = 0.0f;
        est_base_lin_vel[1] = 0.0f;
        est_base_lin_vel[2] = 0.0f;
        return;
    }
    
    // 3. IMU Integration
    float yaw_rate = imu.gyro_z;
    float cos_y = cosf(yaw_rate * dt);
    float sin_y = sinf(yaw_rate * dt);
    
    float vx = est_base_lin_vel[0];
    float vy = est_base_lin_vel[1];
    
    // Rotate
    est_base_lin_vel[0] = vx * cos_y + vy * sin_y;
    est_base_lin_vel[1] = -vx * sin_y + vy * cos_y;
    
    // Integrate Accel (IMU accel is gravity compensated if using LinearAccel feature, check BNO085_IMU)
    // Assuming imu.accel is linear acceleration
    est_base_lin_vel[0] += imu.accel_x * dt;
    est_base_lin_vel[1] += imu.accel_y * dt;
    est_base_lin_vel[2] = 0.0f;
    
    // 4. Fusion
    est_base_lin_vel[0] = (1.0f - EST_VEL_FUSION) * est_base_lin_vel[0] + EST_VEL_FUSION * odom_vel_x;
    
    // 5. Decay
    est_base_lin_vel[1] *= EST_VEL_DECAY;
}

void buildSingleObservation(float* obs) {
    int idx = 0;
    
    // OBSERVATION ORDER MUST MATCH TRAINING (bebop_base_cfg.py ObservationsCfg):
    // [0:3]   base_lin_vel
    // [3:6]   base_ang_vel
    // [6:9]   projected_gravity
    // [9:15]  joint_pos_rel
    // [15:21] joint_vel_rel
    // [21:27] last_action
    // [27:30] velocity_commands
    
    // [0:3] Base Linear Velocity
    obs[idx++] = clamp(est_base_lin_vel[0], -CLIP_LIN_VEL, CLIP_LIN_VEL) * SCALE_LIN_VEL;
    obs[idx++] = clamp(est_base_lin_vel[1], -CLIP_LIN_VEL, CLIP_LIN_VEL) * SCALE_LIN_VEL;
    obs[idx++] = clamp(est_base_lin_vel[2], -CLIP_LIN_VEL, CLIP_LIN_VEL) * SCALE_LIN_VEL;
    
    // [3:6] Base Angular Velocity (IMU)
    obs[idx++] = clamp(imu.gyro_x, -CLIP_ANG_VEL, CLIP_ANG_VEL) * SCALE_ANG_VEL;
    obs[idx++] = clamp(imu.gyro_y, -CLIP_ANG_VEL, CLIP_ANG_VEL) * SCALE_ANG_VEL;
    obs[idx++] = clamp(imu.gyro_z, -CLIP_ANG_VEL, CLIP_ANG_VEL) * SCALE_ANG_VEL;
    
    // [6:9] Projected Gravity
    obs[idx++] = est_projected_gravity[0];
    obs[idx++] = est_projected_gravity[1];
    obs[idx++] = est_projected_gravity[2];
    
    // [9:15] Joint Positions (relative to default)
    for(int i=0; i<4; i++) { // Legs
        obs[idx++] = (joints[i]->current_position - default_joint_pos[i]) * SCALE_DOF_POS;
    }
    obs[idx++] = 0.0f; // Left Wheel (reset - wheels accumulate in real life)
    obs[idx++] = 0.0f; // Right Wheel (reset)
    
    // [15:21] Joint Velocities
    for(int i=0; i<6; i++) {
        obs[idx++] = clamp(joints[i]->current_velocity, -CLIP_DOF_VEL, CLIP_DOF_VEL) * SCALE_DOF_VEL;
    }
    
    // [21:27] Last Action
    for(int i=0; i<6; i++) {
        obs[idx++] = last_action[i];
    }
    
    // [27:30] Velocity Commands (MUST be last to match training!)
    float cmd_vx, cmd_vy, cmd_wz;
    rosPublishers.getCmdVel(cmd_vx, cmd_vy, cmd_wz);
    
    obs[idx++] = cmd_vx * SCALE_LIN_VEL;
    obs[idx++] = cmd_vy * SCALE_LIN_VEL;
    obs[idx++] = cmd_wz * SCALE_ANG_VEL;
}

// ============================================================================
// CAN RECEIVE CALLBACK
// ============================================================================

void canCallback(const CAN_message_t& msg) {
    can_rx_count++;
    if (msg.flags.extended) {
        can_rx_ext_count++;
    } else {
        can_rx_std_count++;
    }
    
    if (can_rx_debug) {
        if (msg.flags.extended) {
            // Robstride extended frame
            uint8_t cmd_type = (msg.id >> 24) & 0x1F;
            uint8_t motor_id = (msg.id >> 8) & 0xFF;
            DEBUG_PORT.printf("RS RX [%08lX] cmd=%02X id=%d len=%d:", 
                              msg.id, cmd_type, motor_id, msg.len);
        } else {
            // ODrive standard frame
            uint8_t node_id = (msg.id >> 5) & 0x3F;
            uint8_t cmd_id = msg.id & 0x1F;
            DEBUG_PORT.printf("OD RX [%03lX] node=%d cmd=%02X len=%d:", 
                              msg.id, node_id, cmd_id, msg.len);
        }
        for (int i = 0; i < msg.len; i++) {
            DEBUG_PORT.printf(" %02X", msg.buf[i]);
        }
        DEBUG_PORT.println();
    }
    
    for (int i = 0; i < NUM_JOINTS; i++) {
        joints[i]->handleCanMessage(msg);
    }
}

// ============================================================================
// WATCHDOG
// ============================================================================

uint32_t last_watchdog_cmd_time = 0;
const uint32_t WATCHDOG_CMD_INTERVAL_MS = 1000;  // Rate-limit watchdog commands to 1Hz

void checkWatchdog() {
    uint32_t now = millis();
    if ((now - rosPublishers.getLastCmdTime()) > WATCHDOG_TIMEOUT_MS) {
        // Rate-limit watchdog commands to avoid flooding CAN bus
        if ((now - last_watchdog_cmd_time) >= WATCHDOG_CMD_INTERVAL_MS) {
            // ODrive wheels: Stop them (they're velocity controlled, so need explicit zero)
            for (int i = ODRIVE_START_IDX; i <= ODRIVE_END_IDX; i++) {
                joints[i]->setCommand(0.0f, 0.0f, 0.0f);
            }
            last_watchdog_cmd_time = now;
        }
    }
}


// ============================================================================
// STATUS REPORTING
// ============================================================================

void printMotorStatus() {
    DEBUG_PORT.println("=== MOTOR STATUS ===");
    DEBUG_PORT.printf("CAN RX (2s): total=%lu (std=%lu ext=%lu)\n", 
                      can_rx_count, can_rx_std_count, can_rx_ext_count);
    
    // Reset CAN counters
    can_rx_count = 0;
    can_rx_std_count = 0;
    can_rx_ext_count = 0;
    
    // Robstride motors
    for (int i = ROBSTRIDE_START_IDX; i <= ROBSTRIDE_END_IDX; i++) {
        RobstrideMotorType* motor = static_cast<RobstrideMotorType*>(joints[i]);
        uint32_t age_ms = millis() - motor->last_feedback_time;
        bool receiving = (age_ms < 500);
        
        DEBUG_PORT.printf("[%d] %s (RS id=%lu): %s | en=%d err=%d (0x%02X) | pos=%.2f vel=%.2f | fb_age=%lums\n",
            i, JOINT_NAMES[i], motor->can_id,
            receiving ? "OK" : "NO CAN",
            motor->is_enabled ? 1 : 0,
            motor->has_error ? 1 : 0,
            motor->getFaultBits(),
            motor->current_position,
            motor->current_velocity,
            age_ms);
    }
    
    // ODrive motors
    for (int i = ODRIVE_START_IDX; i <= ODRIVE_END_IDX; i++) {
        ODriveMotorType* motor = static_cast<ODriveMotorType*>(joints[i]);
        uint32_t age_ms = millis() - motor->last_feedback_time;
        bool receiving = (age_ms < 500);
        
        DEBUG_PORT.printf("[%d] %s (OD node=%lu): %s | state=%d err=0x%08lX | pos=%.2f vel=%.2f | fb_age=%lums\n",
            i, JOINT_NAMES[i], motor->can_id,
            receiving ? "OK" : "NO CAN",
            motor->getAxisState(),
            motor->getAxisError(),
            motor->current_position,
            motor->current_velocity,
            age_ms);
    }
    
    DEBUG_PORT.println();
}

// ============================================================================
// SETUP
// ============================================================================

void setup() {
    // Initialize LED
    pinMode(LED_PIN, OUTPUT);
    digitalWrite(LED_PIN, HIGH);
    
    // Initialize debug serial
    serialCommands.begin(115200);
    delay(500);
    DEBUG_PORT.println("\n=== Teensy CAN Bridge Starting ===");
    DEBUG_PORT.println("Firmware: Bebop Robot micro-ROS Bridge");
    DEBUG_PORT.printf("Joints: %d (Robstride: %d-%d, ODrive: %d-%d)\n", 
                      NUM_JOINTS, ROBSTRIDE_START_IDX, ROBSTRIDE_END_IDX, 
                      ODRIVE_START_IDX, ODRIVE_END_IDX);
    
    // Initialize motors and CAN bus
    DEBUG_PORT.println("Initializing CAN bus...");
    setupMotors();
    DEBUG_PORT.printf("CAN bus initialized: %lu baud, CAN1 (pins TX=22/RX=23)\n", (unsigned long)CAN_BAUD_RATE);

    // Initialize IMU
    DEBUG_PORT.print("Initializing BNO085 IMU... ");
    bool imu_ok = false;
    for (int i = 0; i < 5; i++) {
        if (imu.begin()) {
            imu_ok = true;
            break;
        }
        DEBUG_PORT.print(".");
        delay(200);
    }
    DEBUG_PORT.println(imu_ok ? "OK" : "FAIL");
    
    // Set up CAN callback
    canBus.onReceive(canCallback);

    // Initialize micro-ROS
    if (!rosPublishers.begin(&imu)) {
        // Error loop is handled inside begin()
        while (1) {
            digitalWrite(LED_PIN, !digitalRead(LED_PIN));
            delay(100);
        }
    }

    // Enable all motors
    DEBUG_PORT.println("Enabling motors...");
    for (int i = 0; i < NUM_JOINTS; i++) {
        DEBUG_PORT.printf("  Enabling joint %d: %s\n", i, JOINT_NAMES[i]);
        joints[i]->enable();
        delay(10);
    }
    
    // Enable active reporting on Robstride motors
    DEBUG_PORT.println("Configuring Robstride active reporting...");
    for (int i = ROBSTRIDE_START_IDX; i <= ROBSTRIDE_END_IDX; i++) {
        RobstrideMotorType* rs_motor = static_cast<RobstrideMotorType*>(joints[i]);
        rs_motor->enableActiveReporting(true, 20);  // 20ms interval
    }
    
    policy.init();
    DEBUG_PORT.println("POLICY INITIALIZED (Waiting for activation)");
    last_policy_us = micros();
    last_vel_est_us = micros();
    
    // Initialize timing counters to prevent burst on startup
    uint32_t now = millis();
    last_publish_time = now;
    last_imu_publish_time = now;
    last_diag_publish_time = now;
    last_timing_report_ms = now;
    
    digitalWrite(LED_PIN, LOW);
    DEBUG_PORT.println("=== Teensy CAN Bridge Ready ===\n");
}

// ============================================================================
// MAIN LOOP
// ============================================================================

void loop() {
    uint32_t now = millis();
    uint32_t now_us = micros();
    
    // Process serial debug commands
    serialCommands.update();
    
    // Process CAN messages
    canBus.events();
    
    // Spin micro-ROS executor (non-blocking)
    // Increased timeout to ensure we clear the buffer and handle messages
    rosPublishers.spin(100);  // 1ms timeout
    
    // Update IMU (200 Hz)
    if ((now - last_imu_update_time) >= imu_update_interval_ms) {
        if (imu.initialized) {
            // Check for stale data and attempt hardware reset recovery
            // This uses pin 17 (RST) to reset the BNO085 if data is >2s old
            imu.checkAndRecover(2000);
            
            // Drain IMU queue (handle multiple events if loop is slow)
            int count = 0;
            while (imu.update() && count++ < 10);

            // Always run estimation if policy might be used
            computeProjectedGravity();
            float dt = (now_us - last_vel_est_us) * 1e-6f;
            updateVelocityEstimate(dt);
            last_vel_est_us = now_us;
            
            // IMU debug logging
            if (imu_debug) {
                DEBUG_PORT.printf("IMU: q=[%.3f,%.3f,%.3f,%.3f] gyro=[%.2f,%.2f,%.2f] accel=[%.2f,%.2f,%.2f] grav=[%.2f,%.2f,%.2f]\n",
                    imu.quat_w, imu.quat_x, imu.quat_y, imu.quat_z,
                    imu.gyro_x, imu.gyro_y, imu.gyro_z,
                    imu.accel_x, imu.accel_y, imu.accel_z,
                    est_projected_gravity[0], est_projected_gravity[1], est_projected_gravity[2]);
            }
        }
        last_imu_update_time = now;
    }

    // POLICY CONTROL LOOP
    // Only run if enabled in RosPublishers
    if (rosPublishers.getControlMode() == RosPublishers::MODE_POLICY_BALANCE && (now_us - last_policy_us >= POLICY_INTERVAL_US)) {
        last_policy_us = now_us;
        step_count++;
        
        // Safety Check - only depends on IMU orientation
        bool upright = (est_projected_gravity[2] < -0.5f); // Pointing down (-1)
        
        // ALWAYS run inference if IMU is ready (for debugging/logging)
        if (imu.initialized) {
            // 1. Build Observation
            buildSingleObservation(current_obs);
            updateHistory(current_obs);
            
            // 2. Inference
            policy.infer(history_buffer, action_buffer);
            
            // 3. Store Last Action & Clip
            for(int i=0; i<bebop_policy::ACTION_DIM; i++) {
                last_action[i] = clamp(action_buffer[i], -1.0f, 1.0f);
            }
            
            // 4. Compute scaled commands (for logging)
            float leg_cmds[4];
            float wheel_cmds[2];
            for(int i=0; i<4; i++) {
                float scaled_action = action_buffer[i] * SCALE_ACTION_LEGS;
                leg_cmds[i] = clamp(default_joint_pos[i] + scaled_action, -MAX_LEG_POS_RAD, MAX_LEG_POS_RAD);
            }
            for(int i=0; i<2; i++) {
                wheel_cmds[i] = clamp(action_buffer[4+i] * SCALE_ACTION_WHEELS, -MAX_WHEEL_VEL_RAD_S, MAX_WHEEL_VEL_RAD_S);
            }
            
            // 5. Log actions periodically (every 50 steps = 1 second at 50Hz)
            if (step_count % 50 == 0) {
                DEBUG_PORT.printf("POLICY[%lu]: legs=[%.2f,%.2f,%.2f,%.2f] wheels=[%.1f,%.1f] | UP=%d\n",
                    step_count,
                    leg_cmds[0], leg_cmds[1], leg_cmds[2], leg_cmds[3],
                    wheel_cmds[0], wheel_cmds[1],
                    upright ? 1 : 0);

                // LOG INPUT OBSERVATIONS (First 15 dims)
                DEBUG_PORT.printf("  OBS[0-2] LinVel: [%.3f, %.3f, %.3f]\n", current_obs[0], current_obs[1], current_obs[2]);
                DEBUG_PORT.printf("  OBS[3-5] AngVel: [%.3f, %.3f, %.3f]\n", current_obs[3], current_obs[4], current_obs[5]);
                DEBUG_PORT.printf("  OBS[6-8] Grav:   [%.3f, %.3f, %.3f]\n", current_obs[6], current_obs[7], current_obs[8]);
                DEBUG_PORT.printf("  OBS[9-14] JPos:  [%.2f, %.2f, %.2f, %.2f, %.2f, %.2f]\n", 
                    current_obs[9], current_obs[10], current_obs[11], current_obs[12], current_obs[13], current_obs[14]);
            }
            
            // 6. Only send commands if upright (IMU check)
            if (upright) {
                // Legs (Position)
                for(int i=0; i<4; i++) {
                    joints[i]->setCommand(leg_cmds[i], 0.0f, 0.0f);
                }
                // Wheels (Velocity)
                for(int i=0; i<2; i++) {
                    joints[4+i]->setCommand(0.0f, wheel_cmds[i], 0.0f);
                }
            } else {
                // Safety stop - robot is not upright, zero wheels
                joints[4]->setCommand(0.0f, 0.0f, 0.0f);
                joints[5]->setCommand(0.0f, 0.0f, 0.0f);
            }
        }
    }
    
    // Publish joint state feedback (100 Hz)
    if ((now - last_publish_time) >= publish_interval_ms) {
        rosPublishers.publishState();
        last_publish_time += publish_interval_ms; // Prevent drift
        
        // Blink LED to show activity
        led_state = !led_state;
        digitalWrite(LED_PIN, led_state);
    }
    
    
    // Publish IMU data (100 Hz)
    if ((now - last_imu_publish_time) >= imu_publish_interval_ms) {
        rosPublishers.publishIMU();
        last_imu_publish_time += imu_publish_interval_ms; // Prevent drift
    }
    
    // Publish diagnostics (10 Hz)
    if ((now - last_diag_publish_time) >= diag_publish_interval_ms) {
        rosPublishers.publishDiagnostics();
        last_diag_publish_time += diag_publish_interval_ms; // Prevent drift
    }

    // Check watchdog
    checkWatchdog();
    
    // Print motor status every 2 seconds (if enabled)
    if (status_logging && (now - last_timing_report_ms) >= 2000) {
        // Show current mode in status
        if (rosPublishers.getControlMode() == RosPublishers::MODE_POLICY_BALANCE) {
            DEBUG_PORT.println("[MODE: POLICY_BALANCE]");
        } else {
            DEBUG_PORT.println("[MODE: PASSTHROUGH]");
        }
        
        // IMU diagnostics
        imu.printDiagnostics();
        if (imu.isTimedOut(500)) {
            DEBUG_PORT.println("  WARNING: IMU data is STALE!");
        }
        DEBUG_PORT.printf("Proj Gravity: [%.3f, %.3f, %.3f] (upright=-1.0)\n",
            est_projected_gravity[0], est_projected_gravity[1], est_projected_gravity[2]);
        
        printMotorStatus();
        last_timing_report_ms = now;
    }
}

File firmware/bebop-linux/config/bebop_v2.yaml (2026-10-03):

# ============================================================================
# Bebop V2 (humanoid) joint configuration.
#
# Loaded by `bebop-linux` at startup via `RobotConfig::from_yaml(path)`.
# Schema deliberately matches `ros2/src/bebop_pilot/config/safety_limits.yaml`
# so the same file can later become the single source of truth for both
# the Rust runtime and any ROS2 bridge nodes.
#
# All limits below are *our* safety envelope, not the manufacturer's max.
# Procedure for raising any one of them:
#   1.  Verify the joint can mechanically reach it (manual back-drive).
#   2.  In the dial-in tool, run the relevant test (e.g. vel_probe) at the
#       *current* limit and confirm the motor tracks without faulting.
#   3.  Edit a single field here, raising it by no more than ~25%, re-run.
#   4.  Repeat until you hit a real mechanical / thermal / current ceiling.
# Do not raise multiple limits at once — you lose the ability to attribute
# a fault to the change.
# ============================================================================

defaults:
  hard_limits:
    pos_min: -0.5             # rad — well inside the ±4π motor encoder range
    pos_max:  0.5
    vel_max:  2.0             # rad/s (~115 °/s)
    tau_max:  8.0             # Nm
    temp_max: 65.0            # °C — keep well below firmware overtemp (~85 °C)
    feedback_timeout_ms: 100  # E-STOP if no RX feedback within this window

  # Always-active gains while a motor is "armed" but no test is driving it.
  # Stiffness low; damping > 0 so the motor never goes limp under power.
  hold_gains: { kp: 5.0, kd: 1.0 }

  # Default gains for active tests (currently unused; phase 2).
  test_gains: { kp: 30.0, kd: 2.0 }

  # Setpoint slew limits applied to the *position channel* of the
  # variable-impedance MIT-mode policy output. MUST match
  # `max_pos_step_per_tick` on the sim ActionsCfg in
  # `sim/bebop_training/experiments/exp_standing.py` (currently 0.030).
  # 0.030 rad/tick @ 100 Hz tick = 3 rad/s setpoint slew — the
  # mechanical safety envelope agreed with the operator (relaxed from
  # 2 rad/s Jul 22 2026, round 6: sim showed recovery from ~±0.5 m/s
  # shoves needs catch-step bandwidth 2 rad/s couldn't deliver).
  # Gain channels (kp/kd) are NOT slew-clamped — they are EMA
  # low-passed instead (see the `policy:` block). If you retune this
  # value, retrain.
  slew:
    max_pos_step_per_tick: 0.030   # rad/tick — must match sim exp_standing.py max_pos_step_per_tick
    arm_ramp_s:            0.5     # gain ramp 0 → hold over arm
    abort_ramp_s:          0.3     # gain ramp hold → 0 over abort

  # Policy action-decode parameters. MUST match the sim action term
  # (`VariableImpedanceJointActionCfg` in
  # `sim/bebop_training/envs/bebop_v2_actions.py`).
  policy:
    # First-order low-pass time constant (seconds) applied to the decoded
    # kp/kd channels every 100 Hz tick: g += alpha * (cmd - g) with
    # alpha = 1 - exp(-0.01 / tau). Hard anti-snap guarantee: tick-rate
    # gain flipping is attenuated ~16-30x while slow impedance shifts
    # pass through. MUST equal the `gain_ema_tau_s` the DEPLOYED
    # CHECKPOINT was trained with (sim ActionsCfg in exp_standing.py):
    #   0.15  <- round-4/round-5 checkpoints (incl. run
    #            2026-07-22_23-44-50 ckpt-1500, deployed now)
    #   0.08  <- round-6+ checkpoints (retrained with the relaxed value)
    # Deploying with a mismatched tau makes the motors' gains move at a
    # rate the policy never trained against (oscillation!). 0 disables
    # the filter — never deploy disabled against an EMA-trained policy.
    # Seeded at the per-joint midpoint gains on RunPolicy entry.
    gain_ema_tau_s: 0.15

  # Per-joint policy-emitted kp/kd clamps. The 24-dim MIT-mode action
  # vector carries (8 positions, 8 kp, 8 kd) per tick; the loader
  # affine-maps each raw kp / kd channel from [-1, 1] into the
  # `(kp_min, kp_max)` / `(kd_min, kd_max)` range for its joint. These
  # MUST mirror `POLICY_KP_MIN/MAX` and `POLICY_KD_MIN/MAX` in
  # `sim/bebop_training/envs/bebop_v2_base_cfg.py` — the trained policy
  # baked in this gain envelope. Per-joint overrides (below in the
  # `joints:` block) win over the defaults here.
  #
  # Conservative defaults (overridden per joint group). The loader
  # additionally rejects any clamp that exceeds the motor model's
  # encoder ceiling (`RobstrideSpecs::RSxx.{kp_max, kd_max}` in
  # `firmware/bebop-linux/src/config.rs`).
  # Defaults are the hip_flexion (RS04) values; the four motor groups
  # have per-joint overrides below.
  # Jun 2026 sim-to-real NARROWING (mirror of POLICY_KP/KD_* in
  # exp_standing.py): kp ceilings lowered + bands tightened + kd floors lifted
  # to cut loop gain and per-tick gain-noise so the stand stops ringing on
  # hardware. If you retune one side, retune BOTH and retrain.
  policy_gain_clamps:
    kp_min: 20.0
    kp_max: 120.0
    kd_min: 2.0
    kd_max: 5.0
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

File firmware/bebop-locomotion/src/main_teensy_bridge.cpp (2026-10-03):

/**
 * @file main_teensy_bridge.cpp
 * @brief BNO085 IMU + physical controls -> USB serial bridge for Teensy 4.1
 *
 * Purpose:
 *   Read the BNO085 over SPI (using the shared `BNO085_IMU` driver) and
 *   stream fused orientation + calibrated gyro + linear accel to the host
 *   (Jetson) over USB serial as fixed-size binary frames. This lets the
 *   Jetson consume the IMU through the Teensy instead of wiring the BNO
 *   to the Jetson's own SPI bus.
 *
 *   Also acts as the robot's control input: the Thor has no usable GPIO
 *   header, so buttons (network-mode toggle today, E-stop and more later)
 *   are wired here and forwarded to the Jetson on a dedicated channel.
 *
 *       pio run -e teensy_bridge --target upload
 *
 * Ports (USB_TRIPLE_SERIAL):
 *   Serial      (primary, if00, /dev/bebop-imu)       -> BINARY IMU frames
 *   SerialUSB1  (secondary, if02, /dev/bebop-imu-debug) -> diagnostics
 *   SerialUSB2  (tertiary, if04, /dev/bebop-control)  -> control frames
 *
 *   Keeping binary frames on a dedicated channel means the Jetson parser
 *   never has to filter out log lines, and you can still `cat` the debug
 *   port to watch rates while the bridge runs. The control channel carries
 *   button/event frames (see `include/ControlProtocol.h`) so the Jetson can
 *   read physical controls without a GPIO header (Thor has none) — the
 *   network-mode toggle today, emergency stop and more later.
 *
 * Wiring: identical to `main_imu_spi_test.cpp` / `BNO085_IMU.h`
 *   (BNO over hardware SPI0, INT=37, RST=36, CS=10, PS1=PS0=1 for SPI mode).
 *
 * Button wiring (network-mode toggle): a momentary switch from `BUTTON_PIN`
 *   to GND. The pin uses the Teensy's internal pull-up, so no external
 *   resistor is needed (idle high, pressed low). It is debounced here and
 *   reported on the control port; the Jetson (`bebop-agent`) decides what a
 *   press does.
 *
 * Frame format: see `include/ImuSerialProtocol.h` (IMU) and
 * `include/ControlProtocol.h` (control). The Jetson-side parsers live in
 * `firmware/bebop-linux/src/imu_serial.rs` and
 * `jetson-agent/bebop-agent/src/control_serial.rs`.
 *
 * NOTE: the Teensy streams the RAW sensor-frame quaternion / gyro. The
 * chassis mount rotation is applied on the Jetson (mirroring the SPI
 * path in `imu.rs`) so the two IMU sources are interchangeable.
 */

#include <Arduino.h>
#include "BNO085_IMU.h"
#include "ImuSerialProtocol.h"
#include "ControlProtocol.h"

// 200 Hz emit cadence (5 ms). Decoupled from sensor event arrival: we
// always send the latest cached values, so the host sees a steady stream.
#define EMIT_INTERVAL_US 5000

// Cap sensor events drained per loop so a flood (or a wedged FIFO) can't
// monopolize the loop and starve the emit cadence below.
#define MAX_EVENTS_PER_LOOP 64

// Primary USB serial carries the binary IMU frames; SerialUSB1 is debug.
#define FRAME_PORT Serial
#define DBG_PORT   SerialUSB1
// Control channel (buttons/events) on the third CDC.
#define CTRL_PORT  SerialUSB2

// Network-mode toggle button: switch to GND, internal pull-up (active low).
#define BUTTON_PIN 2
// A level must hold this long before it is accepted as a real edge.
#define BUTTON_DEBOUNCE_MS 30

static_assert(sizeof(ImuSerialFrame) == IMU_SERIAL_FRAME_SIZE,
              "ImuSerialFrame must be 52 bytes (packed) to match the wire format");
static_assert(sizeof(CtrlFrame) == CTRL_FRAME_SIZE,
              "CtrlFrame must be 14 bytes (packed) to match the wire format");

BNO085_IMU imu;

uint32_t seq = 0;
uint32_t last_emit_us = 0;
uint32_t last_stats_ms = 0;
uint32_t frames_sent = 0;

// Control-channel state.
uint8_t  ctrl_seq = 0;
uint32_t buttons_pressed = 0;
bool     button_raw = false;       // last raw active-high read
bool     button_stable = false;    // debounced active-high state
uint32_t button_last_edge_ms = 0;

void emitFrame() {
    ImuSerialFrame f;
    f.seq = seq++;
    f.t_us = micros();

    // BNO085_IMU stores the quaternion as (w, x, y, z); the wire format is
    // XYZW (scalar last) to match the Jetson's ImuSnapshot contract.
    f.quat_xyzw[0] = imu.quat_x;
    f.quat_xyzw[1] = imu.quat_y;
    f.quat_xyzw[2] = imu.quat_z;
    f.quat_xyzw[3] = imu.quat_w;

    f.gyro_xyz[0] = imu.gyro_x;
    f.gyro_xyz[1] = imu.gyro_y;
    f.gyro_xyz[2] = imu.gyro_z;

    f.accel_xyz[0] = imu.accel_x;
    f.accel_xyz[1] = imu.accel_y;
    f.accel_xyz[2] = imu.accel_z;

    imu_serial_finalize(&f);

    FRAME_PORT.write((const uint8_t*)&f, sizeof(f));
    frames_sent++;
}

// Emit one control frame on the control CDC. Payload is type-specific;
// button frames pack (state << 8) | id.
void emitControl(uint8_t type, uint32_t payload) {
    CtrlFrame f;
    f.type = type;
    f.seq = ctrl_seq++;
    f.t_us = micros();
    f.payload = payload;
    ctrl_finalize(&f);
    CTRL_PORT.write((const uint8_t*)&f, sizeof(f));
}

void emitButton(uint8_t button_id, bool pressed) {
    uint32_t payload = ((uint32_t)(pressed ? CTRL_BUTTON_PRESSED
                                            : CTRL_BUTTON_RELEASED) << 8) | button_id;
    emitControl(CTRL_MSG_BUTTON, payload);
    if (pressed) {
        buttons_pressed++;
    }
}
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

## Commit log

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2026-04-30 chore(jetson-agent): annotate scaffolding dead-code so clippy passes
    Several items exist as forward-looking scaffolding for subsystems that
    are not yet wired through the BLE protocol layer, but they tripped
    `-D dead_code` and broke `just lint` on a clean checkout.
    Marks each one `#[allow(dead_code)]` with a one-line comment naming the
    follow-up work that will consume it, rather than deleting them or
    loosening the lint level globally:
    - `error::Result<T>` alias — kept for the eventual subsystem -> proto
    error mapping.
    - `AgentError::{NotImplemented, Unauthorized, Ota, Ble}` — emitted once
    the dispatcher learns method coverage, the auth handshake lands, and
    OTA/BLE faults flow back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
    [mod.rs]
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2026-05-01 feat(jetson-agent): make app.image opt-in, idle supervisor on missing
    A fresh install with no /etc/bebop/agent.toml (or with [app] image
    unset) used to fall back to a compiled-in placeholder
    "nvcr.io/your-org/bebop-app:latest" and enter a tight 401-loop in
    the container supervisor. Switch image to Option<String> with a None
    default so:
    - config: AppConfig.image is Option<String>; default_app_image is
    removed; serde default gives None.
    - containers::run: restructured into a single loop that idles
    silently (with one info log) when image is None, bootstraps once
    when image becomes Some, and reconciles thereafter. Tracks both
    states so OTA flipping image None<->Some at runtime re-bootst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
    [mod.rs]
2026-05-01 feat(bebop-app): speak protobuf over BLE, sharing schema with the agent
    The Bebop mobile app and the Jetson agent share a single proto schema
    (jetson-agent/bebop-proto/proto/bebop.proto), but the app was framing
    JSON envelopes ({ requestId, ... }) on the wire while the agent decodes
    those bytes as a prost-generated bebop.v1.ClientRequest. Every write
    from the phone tripped a "ClientRequest.payload: invalid wire type:
    StartGroup (expected LengthDelimited)" decode error in the agent's BLE
    server, because '{' (0x7B) decodes as a tag for field 15 (the
    get_robot_config oneof arm) with wire type 3.
    Wire both transports onto the protobuf schema instead:
    - bebop-app/src/proto/: generated with @buf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
    [mod.rs]
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2026-05-01 feat(jetson-agent): persist agent.toml on BLE-driven config edits
    Today set_robot_config only mutated the in-memory RwLock<AgentConfig>;
    any change made from the app was lost on the next agent restart. This
    adds a small persistence path that:
    - Adds config::config_path() and config::save() in
    bebop-agent/src/config/mod.rs. save() does an atomic temp-file write
    with fsync + rename so a crash mid-write can't leave a half-written
    config behind. (Comments in the shipped template are lost on first
    rewrite; toml_edit-based surgical updates can be a follow-up.)
    - Introduces a mutate_and_persist() helper in the BLE dispatcher that
    clones the current AgentConfig, applies the requested muta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
    [mod.rs]
2026-05-01 fix(bebop-app): make BLE transport reliable and friendly
    A handful of bugs surfaced while exercising the setup flow on real
    hardware. They all sit in the BLE transport layer and the screens that
    drive it; bundling here so each individual fix has the others as
    context.
    Tauri / btleplug central (src-tauri/src/ble/central.rs):
    - Open the notification stream synchronously inside connect() before
    returning, instead of inside the spawned reader task. btleplug's
    notifications() returns a fresh receiver on a per-peripheral
    broadcast channel; messages received before the receiver exists
    aren't buffered, so the response to the very first request after
    connect was being dropped on the floor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
    [mod.rs]
2026-05-01 feat(bebop-app): edit container image and control the app from the dashboard
    The dashboard now exposes everything you need to keep the robot's
    container in sync with what's in /etc/bebop/agent.toml without SSHing
    into the device.
    Transport plumbing (proto-regenerated bindings + interface):
    - BebopTransport.setAppImage(image) sends the new SetAppImageRequest
    added to the agent in 2ee691d. Returns the live AppStatus so the UI
    can render the change immediately. Empty string clears the image
    (supervisor goes idle), matching the existing CLI behaviour.
    - Web Bluetooth and Tauri implementations.
    - Tauri side adds the ble_set_app_image command and registers it in
    the invoke handler.
    Dashb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
    [lib.rs, mod.rs]
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2026-05-05 feat(bebop-linux): rewrite as v2 multi-mode runtime with WS API
    Replaces the single-purpose 50 Hz policy loop with a multi-mode server
    (Idle / DialIn / RunPolicy) driven by the new bebop.runtime.v1 protobuf
    API over WebSocket. Adds:
    - Library crate (lib.rs) exposing config, mode, safety, server, powerboard.
    - YAML-driven RobotConfig (config/bebop_v2.yaml) — the single source of
    truth for joints, hard limits, slew, hold/test gains, and (optional)
    power-board telemetry. Hardcoded defaults removed.
    - Safety supervisor: per-joint outgoing clamp, slew limit, incoming-frame
    check, feedback watchdog, and a Drop impl that disables every motor on
    every bus before exit.
    - Robstride PowerBoa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
    [bebop_v2.yaml, config.rs, lib.rs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]
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2026-05-06 fix(ci): satisfy cargo fmt and clippy --workspace -- -D warnings
    - firmware: apply rustfmt across recent changes
    - firmware: fix clippy lints (iter_cloned_collect, let_and_return,
    useless_vec, needless_range_loop)
    - jetson-agent: replace evdev::KeyCode::BTN_GAMEPAD/BTN_JOYSTICK (not
    exported in evdev 0.13) with their canonical aliases BTN_SOUTH/
    BTN_TRIGGER
    - jetson-agent: fix clippy manual_is_multiple_of and silence
    intentionally-unused public APIs with #[allow(dead_code)]
    [can_interface.rs, config.rs, main.rs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]
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2026-05-08 feat(bebop-app): Bluetooth gamepad dial-in + mobile motor bench
    Adds a Web Gamepad API driver that lets a phone- or laptop-paired
    controller drive the active joint's target on the motor bench, with
    auto-detection between standard and dinput HID layouts. Reworks the
    motor bench and IP-connect screens for phone-sized viewports
    (stacked motor cards, full-width segmented mode switcher, prominent
    E-STOP, hostname-friendly IP input). Firmware gets per-joint
    hold_gains so joints can actually hold their commanded position
    under load instead of falling back to the weak kp=5/kd=1 default.
    [bebop_v2.yaml]
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2026-05-10 docs(ros2,sim): document URDF->USD pipeline and add helper scripts - ros2/src/bebopv2_description/scripts/xacro-to-urdf.sh: regenerate bebopv2.urdf from bebopv2.xacro and rewrite every <mesh filename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
    [bebopv2.urdf]
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2026-05-10 feat(bebop-v2): end-to-end ONNX policy inference on bebop-linux
    - firmware/bebop-linux: new policy_runner module owns a PolicyController
    + ObservationBuilder and is driven from the existing 100 Hz tick loop
    via Mode::RunPolicy. Loads policy.onnx from <config_dir>/policy.onnx
    by default (override with --policy). Soft-fails when the file is
    absent so DialIn / Idle still work without a model on disk. On enter
    it resets the policy's history buffer and last-action cache; on
    inference / shape errors it latches E-STOP through the supervisor.
    - firmware/bebop-linux/src/observation.rs: full rewrite for V2 humanoid
    (8 leg joints, no wheels) with the 36-dim observation layout matching
    b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
    [bebop_v2.yaml, config.rs, lib.rs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]
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2026-05-10 firmware,app: make RunPolicy mode actually drivable The policy runner doesn't enable motors itself, but set_mode disarmed every joint on the DialIn->RunPolicy transition and arm() refused outside Dia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
    [policy_runner.rs, supervisor.rs]
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2026-05-12 Configure IMU mount orientation
    Apply the BNO08x sensor-to-body mount rotation in firmware, normalize published IMU quaternions, and update the orientation widget to render body-frame attitude correctly.
    [bebop_v2.yaml, config.rs, imu.rs]
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2026-05-12 firmware(bebop-linux): migrate IMU from I²C/0x05 to SPI/0x28
    The previous IMU path opened /dev/i2c-7, used the `bno080` crate, and
    asked the BNO085 for SH-2 report 0x05 (the plain magnetometer-fused
    rotation vector). It worked on the bench but locked up near the leg
    motors: brushless drive currents bias the BNO's magnetometer enough
    that 0x05's fusion filter rejects all subsequent mag updates,
    freezing yaw indefinitely until a hard reset. The yaw widget on the
    operator app dial-in screen would just stop responding while
    roll / pitch kept tracking normally.
    The fix is to migrate to SPI (so we have a dedicated INT line for
    low-latency reads) and subscribe to SH-2 report 0x28 ("AR/VR-
    Stabili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
    [bebop_v2.yaml, config.rs, imu.rs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]
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2026-05-13 feat(bebop-v2): train balance policy on IMU observations and consume live BNO at runtime
    Sim: switch the policy's `base_ang_vel` and `projected_gravity`
    observation terms from articulation ground-truth to the explicit
    `ImuCfg` sensor mounted on `base_link` with identity offset, so the
    training observation pipeline matches the BNO085 pipeline on the
    robot. Use Isaac Lab 3.0's XYZW quaternion identity (0, 0, 0, 1) in
    the `OffsetCfg`. Tune `exp_flat_balance_robust_v2` with a small
    initial roll/pitch tilt so `leg_action_when_stable` only credits the
    policy when it has genuinely re-centred, and document the two-stage
    curriculum (Flat -> FlatRobust with --reset_action_std). Teach
    `_ensure_tensor`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
    [imu.rs, main.rs, policy_runner.rs]
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2026-05-15 bebop-v2: retrain balance policy with leg-compensation reward
    Sim:
    - New `torso_upright_via_legs_reward`: reads body-frame projected gravity
    from the IMU sensor and rewards the pitch component being offset by
    the average ankle AND knee joint angles, leaving roll penalised
    directly. Multiplicative `exp(-(pitch_residual^2 + roll^2) / std^2)`
    shaping in [0, 1]. Wired into `RewardsCfg` at weight 1.0.
    - Aligned hip_abduction (85/5 -> 40/3) and femur (40/4 -> 160/6) PD
    gains with the firmware yaml `hold_gains` to close the largest piece
    of the sim-to-real torque mismatch driving observed hip/torso
    oscillation in deployment.
    - Tightened action slew to 0.125 rad/tick (12.5 rad/s) so it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
    [bebop_v2.yaml]
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2026-05-15 firmware(imu): retry SHTP bring-up forever + graceful disable on shutdown
    Move SPI/GPIO open, SHTP init, and 0x28 SET_FEATURE inside the
    spawned thread with exponential backoff (250 ms..5 s) so a wedged
    or slow-booting BNO no longer prevents the runtime from starting.
    Log severity demotes after the first few failures to keep
    journalctl readable. On shutdown, disable reports 0x28 / 0x02
    (period=0 µs) so the chip stops streaming into a dead bus — this
    is what keeps the *next* bring-up from racing stale subscriptions
    during verify_product_id. Mirror the graceful-disable in imu-probe
    so back-to-back probe runs don't burn the retry budget either.
    [imu.rs, imu_probe.rs]
2026-05-15 firmware(can): decode Robstride velocity/torque against per-model full-scale
    parse_robstride used a hardcoded ±15 rad/s and ±120 Nm range for
    every motor, which silently inflated telemetry on the smaller
    RS02/RS03 joints by up to ~7×. Forward velocity/torque as raw u16
    on the feedback struct and add `velocity(&specs)` / `torque(&specs)`
    accessors that decode against the motor's RobstrideSpecs. Hoist
    uint16_to_float to a free function so the encode/decode reciprocity
    can be unit-tested across all four models, including the cross-model
    "wrong specs" case that asserts the expected inflation ratio.
    [can_interface.rs, robstride.rs]
2026-05-15 firmware(safety): latch E-STOP on Robstride fault frames, accept active-reports
    Add a MotorFaultReport BreachReason carrying the raw 8-byte payload
    plus best-effort decode of the status bits visible in the CAN ID.
    Wire the RX thread to dispatch on cmd_type: 0x02 / 0x18 go through
    on_feedback (active-report shares the feedback wire format), 0x15
    triggers on_fault_report and latches E-STOP, anything else from a
    known motor is debug-logged. Previously 0x15 was dropped on the
    floor and a faulted motor only surfaced via the feedback watchdog
    seconds later. check_feedback now resolves velocity/torque against
    the joint's RobstrideSpecs (matches the new can_interface decode).
    [limits.rs, supervisor.rs]
2026-05-15 config(bebop_v2): pin firmware tau_max to sim FW_*_TAU_MAX (trained envelope)
    Update the rationale comments on both sides to make explicit that
    the supervisor's hard_limits.tau_max MUST equal the matching
    FW_*_TAU_MAX in bebop_v2_base_cfg.py — the policy was trained
    against exactly that envelope (effort_limit_sim), so any drift
    means deploy-time torques the policy didn't see or supervisor
    trips on torques it was trained to use. Document the per-group
    sizing relative to each Robstride model's electrical peak
    (RobstrideSpecs::RSxx.torque_max).
    Also tighten slew.max_pos_step_per_tick from 12.5 -> .01 rad.
    [bebop_v2.yaml]
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2026-05-17 sim+firmware: MIT-mode variable impedance and aligned 0.015 slew
    Train and deploy a 24-dim action (pos, kp, kd per joint) with sim-side
    stiffness/damping writes and firmware decode into safe_send_ctrl. Bump
    obs to 52 and action to 24; load policy_gain_clamps from YAML with
    encoder-safe validation. Retire fixed sim FW_* PD constants; document
    the contract in README. Keep PPO Gaussian std_type scalar for this
    rsl_rl build.
    [bebop_v2.yaml, config.rs, policy_runner.rs]
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2026-05-21 sim(bebop-v2): minimal standing experiment + 7kg torso mass correction Bench measurement showed the real torso is 7.0 kg, not the 10.5 kg the CAD-derived USD claimed. Combined with the kitchen-sink c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
    [bebopv2.xacro]
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2026-05-21 Stream policy observation/action to the operator app
    Adds a PolicyIoStats proto field on TelemetryFrame/Snapshot carrying the
    52-dim observation, 24-dim raw NN output, and decoded MIT targets/kp/kd
    from each PolicyRunner tick. PolicyRunner publishes to a shared
    PolicyIoSnapshot every cycle (100 Hz); the WS telemetry pump reads the
    latest at ~30 Hz.
    The operator app renders this in a new PolicyIoCard with per-signal
    sparklines and a configurable 5s / 15s / 30s history window. A "Clear"
    button wipes buffers in place so a fresh run can be screenshotted
    without leaving RunPolicy, and a "Frozen" indicator replaces "Active"
    when telemetry stops arriving so stopped runs stay visible.
    Also fixes a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
    [lib.rs, main.rs, policy_runner.rs]
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2026-05-22 Harden BNO085 SPI warm-restart bring-up for unreliable IMU recovery.
    Extend vendored reset timing (50 ms drain, 10 ms RST hold, 500 ms HINTN wait),
    add IMU-thread pre-reset GPIO pulse and 1 s bring-up backoff floor, and add
    regression tests so reset constants cannot shrink silently on re-vendor.
    [imu.rs]
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2026-06-02 firmware(bebop-locomotion): BNO085 SPI driver, 200Hz reports, USB IMU bridge
    Migrate the BNO085 driver from I2C to SPI (dedicated INT line, AR/VR
    stabilized RV 0x28) and bump the requested report rate from 100Hz to
    200Hz. Add an `imu_bridge` build that streams fused orientation + gyro +
    accel to the Jetson over USB serial as fixed 52-byte binary frames
    (see ImuSerialProtocol.h), plus the standalone SPI/I2C IMU test programs
    and their PlatformIO envs.
    [BNO085_IMU.h, main_imu_bridge.cpp]
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2026-06-02 fix(imu): INT-gate BNO085 reads so the SPI stream runs at 200Hz
    getSensorEvent() -> sh2_service() unconditionally calls the SPI HAL read,
    which busy-waits up to 500ms on the INT line (and hardware-resets the chip)
    when the FIFO is empty. Polling it on empty stalled the loop to ~5Hz,
    starving the bridge's 200Hz emit cadence and the standalone SPI test.
    Gate getSensorEvent() on INT being asserted (LOW) in both BNO085_IMU::update()
    and the standalone test so reads happen only when a report is ready.
    Also make the sensor-reset path non-blocking: drop delay(50) and throttle
    report re-enable so a boot-looping chip can't monopolize the loop. Surface
    init/reset_count in the bridge debug line.
    [BNO085_IMU.h, main_imu_bridge.cpp]
2026-06-03 Add actuator system-identification tooling
    Add a standalone `sysid` Rust binary to the bebop-linux crate that drives a
    single Robstride actuator through excitation maneuvers (friction-sweep,
    torque-step/chirp, noload-speed, stall-torque) and logs synchronized CAN
    feedback to CSV. Reuses the existing motor stack but bypasses the
    Supervisor/WS server for full MIT-mode control, with a self-contained safety
    envelope, a required --setup gate (bench/hanging/stand), and gated
    --allow-cap-override for the T-N-curve maneuvers.
    Add sim/bebop_training/tools/sysid_fit.py to fit the four Isaac Lab
    DCMotorCfg parameters (friction, armature, velocity_limit, saturation_effort)
    from the logs and emit ready-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
    [sysid.rs]
2026-06-03 Apply sysid-measured actuator params + harden sysid tool
    Plug sysid-measured Coulomb friction and reflected rotor inertia (armature)
    into the four DCMotorCfg groups in exp_standing.py (right-side bench runs),
    keeping stall torque / no-load speed at datasheet values (encoder-saturated /
    unblocked on the bench). Add a randomize_joint_parameters reset event that
    scales friction x[0.7,1.4] and armature x[0.9,1.1] about the measured nominal.
    Harden the sysid binary: split immediate (fault/comms) vs debounced kinematic
    aborts with an impossible-temperature sanity band, and add a bench-only
    --free-spin flag that relaxes the position/velocity limits for a free shaft.
    Include the raw sysid CSV logs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
    [sysid_foot_right_joint_friction_sweep_20260603_032421.csv, sysid_foot_right_joint_noload_speed_20260603_032300.csv, sysid_foot_right_joint_stall_torque_2026060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]
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2026-06-12 feat(bebop-linux): MCAP policy capture + dry-run, drop gyro_live signal
    Operator-toggled observation/action capture for noise review and sim
    playback, plus a "dry run" flag that lets the policy infer + record
    without driving the actuators.
    bebop-linux
    - New `policy_capture` writer thread: bounded mpsc + dedicated
    `mcap::Writer<BufWriter<File>>` with Zstd chunks, off the 100 Hz
    control loop. Tick thread builds a `PolicyCaptureSample` proto and
    `try_send`s it; backlog is surfaced as `capture_dropped` (never
    blocks the loop).
    - New `policy_control` shared flags for `dry_run` + `capture_requested`
    +`capture_label`, written by the WS handler and consumed by the runner.
    - `policy_runner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
    [imu.rs, imu_serial.rs, lib.rs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]
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2026-06-13 feat(bebop-linux): always-on MCAP capture with size-based rotation, HTTP downloads, and WS auto-reconnect
    Capture now runs automatically whenever the runtime is in DIAL_IN or
    RUN_POLICY and is not E-STOPped; the operator no longer toggles it.
    The writer auto-rotates the active file at 256 MiB and prunes oldest
    segments to keep the capture dir under a 4 GiB total budget, so a
    robot left on for hours never fills the eMMC. The runner throttles
    its open requests to once every 5 s and the writer dedupes identical
    failure logs over a 30 s window so a persistent open error (e.g. a
    read-only fs) doesn't flood the journal at 100 Hz.
    Removed:
    - SetPolicyCapture proto message (tag 12 reserved on
    Cli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
    [main.rs, policy_capture.rs, policy_runner.rs]
2026-06-14 Fix ROS2/CDR MCAP capture for Foxglove and improve review layouts
    CDR encoder (firmware):
    - Write little-endian encapsulation header (00 01 00 00); the prior
    byte order was misread as big-endian, corrupting every field.
    - Align float64/uint64 to 8 bytes relative to the body start (was 4),
    matching classic CDR / Foxglove's reader.
    - Correct std_msgs/Header schema to the ROS2 layout (drop phantom seq,
    use builtin_interfaces/Time).
    Capture content (firmware):
    - Use canonical observation::JOINT_NAMES so Foxglove's URDF panel maps
    joint_states to URDF joints and animates the model.
    - Tag joint_states with frame_id "base_link" (URDF root) to resolve the
    3D panel's fixed/display frame.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
    [cdr.rs, lib.rs, mod.rs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]
2026-06-15 fix(standing): resolve sim-to-real oscillation + balance for quiet stand
    Root causes found and fixed across sim + firmware:
    - Joint-order bug: Newton resolves joints right-before-left per pair while
    firmware uses left-before-right, so deployed policies were L<->R mirror
    swapped. Pin preserve_order=True on the action + joint_pos/joint_vel obs
    terms and assert the resolved order matches JOINT_NAMES_ALL.
    - Oscillation: policy rode the 0.020 rad/tick slew limiter as a bang-bang
    controller. Strengthen position_rate (-0.05->-0.30) and gain_rate
    (-0.10->-0.20); add joint_vel_l2.
    - Sim-to-real robustness: per-episode randomized action latency
    (action_delay_range), sensor noise on projec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
    [bebop_v2.yaml, config.rs]
2026-06-16 fix(firmware): correct reversed hip_abduction encoder polarity
    The two RS03 hip-abduction motors are mounted/zeroed with the opposite
    rotation polarity from the URDF/sim convention: a passive back-drive
    capture (policy off) showed manual inward adduction reading as positive
    (= URDF outward splay), confirmed against the matching USD abduction axis.
    This sign-flipped both the policy's joint_pos observation and its position
    commands relative to training.
    Add a per-joint `direction` (+1/-1, default +1) to the joint config and
    apply it at the supervisor's motor<->robot boundary: feedback
    position/velocity/torque are converted on RX (on_feedback), outgoing
    setpoints on TX (safe_send_ctrl), and th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
    [bebop_v2.yaml, config.rs, supervisor.rs]
2026-06-17 fix(firmware): flip reversed hip_flexion and knee_flexion encoder polarity
    Two more passive back-drive captures (policy off) showed the same
    reversed-encoder issue as the hip-abduction joints: legs bent back by hand
    rendered as URDF forward, and knees bent forward rendered as URDF backward.
    Forward-kinematics on the logged joint signs confirmed both against the
    URDF/sim convention.
    Set direction: -1 on hip_flexion_left/right_joint and
    knee_flexion_left/right_joint in bebop_v2.yaml (knee hard_limits are
    symmetric, so the flip is limit-safe). The ankle/foot joints bend correctly
    and stay +1. No runtime code change is needed — the direction handling
    landed with the abduction fix and is data-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
    [bebop_v2.yaml, config.rs]
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2026-07-13 feat(standing): pin gains and migrate Isaac Lab beta2
    Align simulation and firmware limits for fixed-gain standing, simplify reward shaping, and update container and training workflows for the beta2 runtime.
    [bebop_v2.yaml]
2026-07-13 feat(mirror): pose mirror from bebop-linux WebSocket telemetry
    Add a sim-side pose mirror that teleports the Isaac Lab articulation to
    match live hardware joint positions and IMU orientation streamed over the
    bebop-linux runtime WebSocket API. Intended for visual joint validation
    without running the policy in the loop.
    - mirror_bebop.py: connects to ws://<robot>:9090, subscribes to
    TelemetryFrame, writes joint + root state each sim tick.
    - Isaac-BebopV2-Mirror-v0 env: single env, gravity off, zero-gain
    actuators, base pinned at spawn.
    - runtime_ws.py: background WS client (binary protobuf, auto-reconnect).
    - Python proto bindings for bebop_runtime.proto.
    - Backward-compat joint gat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
    [bebop_v2.yaml, lib.rs, limits.rs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]
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
